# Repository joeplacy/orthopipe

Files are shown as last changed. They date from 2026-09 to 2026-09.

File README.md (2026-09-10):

# OrthoPipe

OrthoPipe is a production-oriented internal tool for orthotics fabrication labs. It turns a
3D foot scan plus a structured or free-text prescription into a validated, reviewer-approved,
print-ready orthotic STL with a traceable record from intake through approval.

The repository is an engineering prototype, **not yet a production or clinically validated
system**. Synthetic geometry passes today; real-world calibration, workflow validation, access
control, durable storage, and printer/material process validation remain release gates. See
[`docs/production-readiness.md`](docs/production-readiness.md).

## What exists

- Scan cleanup, canonical alignment, heightfield shell generation, prescription modifications,
  variable-stiffness lattice support, geometric checks, and a pressure proxy.
- FastAPI review station for upload, prescription review, generation, approval, download,
  complaint capture, and replay scorecards.
- Cloud and explicitly selected local Rx-parser backends.
- Historical-order replay/diff harness and landmark calibration tools.
- Deterministic bilateral print preparation with multi-body STL and manufacturing manifest.
- Offline Rx evaluation fixtures and a stdlib regression suite.
- De-identification guards for replay inputs and phone-scan normalization helpers.

## Local setup

Requires Python 3.11. The dependency versions in `requirements.txt` are pinned to the validated
baseline.

```bash
make setup
make verify
make demo
```

To start the local review station:

```bash
# Use .env.example as a reference; export overrides in your shell/process manager.
make serve
```

The server binds to `127.0.0.1:8000` by default. `ORTHOPIPE_DATA_DIR` moves runtime uploads and
outputs outside the source tree. Do not expose the server to a network until authentication,
authorization, TLS, and durable audit storage are implemented.

## Common commands

| Command | Purpose |
|---|---|
| `make verify` | Unit tests, parser self-check/offline evaluation, replay identity check |
| `make demo` | Full synthetic scan → STL run for both feet |
| `make print-prep-demo` | Generate, orient, pair, and manifest the two demo orthoses |
| `make replay-synthetic` | Five-order replay/diff exercise in `outputs/replay/` |
| `python -m eval.score_rx --offline` | Score cached parser fixtures without an API key |
| `python -m landmarks --help` | Landmark measurement/calibration commands |

## Rx parsing and PHI

Geometry and offline evaluation require no model API key. Live parsing defaults to Anthropic and
requires `ANTHROPIC_API_KEY`; the local Ollama path is selected explicitly with
`ORTHOPIPE_RX_BACKEND=local`. Never commit keys or paste patient-identifying data into fixtures.
Before real PHI is processed, complete the data-handling controls in
[`docs/data-handling.md`](docs/data-handling.md) and confirm appropriate vendor agreements.

## Historical calibration input

The replay harness consumes one directory per de-identified order containing:

- `order.json` — non-identifying order ID, side, and optional shell settings
- `rx.json` — structured prescription
- `scan.obj`, `scan.stl`, or `scan.ply` — original scan geometry
- `reference.stl` — fabricator-approved final device

Start with [`examples/deidentified-order/README.md`](examples/deidentified-order/README.md).

## Repository map

| Path | Role |
|---|---|
| `schema.py` | Validated prescription contract |
| `geometry.py` | Cleanup → alignment → shell → mods → validation → export |
| `lattice.py` | Optional zoned lattice generation |
| `rx_parser.py`, `rx_backends.py` | Free-text prescription parsing |
| `app.py`, `static/index.html` | Review-station API and UI |
| `replay.py` | Historical replay and geometric scorecards |
| `print_prep.py`, `workflow.py` | Bilateral build layout and confirmed production states |
| `landmarks.py` | Landmark measurement and calibration |
| `eval/` | Offline parser evaluation |
| `tests/` | Fast regression and safety tests |
| `docs/` | Strategy, discovery, data handling, and readiness gates |

## Print preparation

The confirmed fabricator workflow stands each completed FO with its forefoot upward, places the
medial faces toward the center without contact, combines both objects for export, embeds them
`0.3 mm` into the Simplify3D bed, and generates supports at a `23°` threshold. OrthoPipe automates
the deterministic geometry portion and records the slicing values without pretending to generate
or approve G-code:

```bash
python print_prep.py \
  --left ORDER_left.stl \
  --right ORDER_right.stl \
  --order-id ORDER \
  --out outputs/ORDER_print_pair.stl \
  --profile config/print-prep.example.json
```

The output includes a multi-body STL, front/top layout preview, and JSON manifest. The manifest
deliberately blocks G-code release until supports, slicing, and visual toolpath QC are completed.
Printer bed dimensions remain unset—and bed fit is reported as unknown—until the real factory
profile is available.

## Product direction

The intended operating model is an internal tool for fabrication labs, with production readiness
rather than a demo as the objective. Fabricator workflow discovery and representative historical
orders are acknowledged inputs to later gates; they are not silently replaced with assumptions.

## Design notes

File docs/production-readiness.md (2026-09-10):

# Production readiness plan

## Product boundary

OrthoPipe is intended to be an **internal fabrication-lab tool**. A trained reviewer remains in
the loop and owns approval. The software may translate clinical intent and generate geometry, but
it must not silently resolve ambiguous prescriptions or present a geometric check as proof of
clinical effectiveness.

The current repository is a validated engineering baseline, not a production release.

## Release gates

### Gate 0 — Reproducible engineering baseline

Status: **implemented locally; CI activates after the repository is pushed.**

- Imported work captured in version control.
- Python version and direct runtime dependencies pinned.
- One-command verification (`make verify`) and full synthetic demo (`make demo`).
- Unit/contract checks for schema ranges, mutable defaults, scale normalization, PII scrubbing,
  parser dispatch, health reporting, and replay path handling.
- GitHub Actions workflow for every pull request and main-branch push.
- Runtime host, port, data directory, and upload-size limit are configurable.

### Gate 1 — Fabricator workflow confirmed

Status: **partially documented.** The intake, Meshmixer orientation/layout, Simplify3D support,
toolpath review, and G-code handoff path are captured in
[`fabricator-workflow-current-state.md`](fabricator-workflow-current-state.md). The separate
prescription-modification procedure, timings, exception paths, acceptance rules, equipment, and
system ownership remain outstanding.

Observe real work rather than relying only on an interview. Complete
[`workflow-discovery.md`](workflow-discovery.md), including the happy path, exception paths,
handoffs, decision authority, artifacts, timings, queue states, rework, and acceptance criteria.

Exit evidence:

- Current-state swimlane reviewed by the people who do the work.
- Measured baseline for touch time, elapsed time, first-pass yield, remake rate, and queue age.
- Explicit list of decisions OrthoPipe may automate, recommend, or must leave to a reviewer.
- Scanner, CAD, slicer, printer, material, and job-tracking integration inventory.

### Gate 2 — Historical calibration and technical validation

Status: **waiting for de-identified representative orders and physical process inputs.**

Use the replay format in [`examples/deidentified-order/`](../examples/deidentified-order/) and
sample across common device/Rx types, operators, scan sources, and known difficult cases.

Exit evidence:

- Dataset inclusion/exclusion rules and provenance recorded.
- Landmark error and geometric deviation thresholds approved by domain experts.
- Parser evaluation uses real, de-identified prescriptions and real model outputs—not placeholder
  fixtures.
- Printed coupon testing maps lattice family/density to the actual TPU, printer, orientation, and
  slicer profile.
- Generated devices are compared with accepted devices and destructive/bench tests where needed.
- Failure cases reliably stop for manual review.

### Gate 3 — Controlled lab pilot

Status: **not started.**

- Durable database/object storage replaces the in-memory job registry.
- Authentication, roles, reviewer identity/signature, session management, and least privilege.
- TLS, secrets management, backup/restore, retention/deletion policy, and audit export.
- Malware/file validation, resource limits, worker isolation, retry/idempotency, and job recovery.
- Approved scanner ingestion, slicer profile, printer/material lot tracking, and output labeling.
- Monitoring covers job failures, queue age, validation failures, approval latency, and storage.
- Rollback, incident response, complaint handling, and support ownership are rehearsed.
- Pilot runs in shadow mode before any generated output is used operationally.

### Gate 4 — Production release

Status: **not started.**

- Pilot exit thresholds met for a pre-agreed sample size and time period.
- Risk management, software validation, change control, training, and work instructions approved.
- Regulatory counsel confirms classification, establishment obligations, quality-system scope,
  complaint/MDR handling, labeling, and records requirements for the actual business model.
- Security/privacy review and any required BAAs or other vendor agreements are complete.
- Named owners exist for product, clinical/fabrication validation, quality, security, operations,
  and incident response.

## Decisions intentionally deferred

These choices should follow workflow discovery rather than be baked into the prototype:

- Job/status data model and integrations.
- Whether the unit of work is a patient, encounter, order, pair, foot, device, or print job.
- Required reviewer roles and approval/signature sequence.
- Scanner and CAD interoperability priorities.
- Automatic slicer/printer dispatch versus reviewed export.
- Lab-specific geometry defaults and allowed adjustment ranges.

## Current technical limitations

- `SCANS` and `RESULTS` are process memory and are lost on restart.
- Audit and complaint records are local JSONL, not transactional or access-controlled.
- No authentication, authorization, tenant separation, electronic signatures, or TLS termination.
- Upload processing is synchronous and geometry work is not isolated in a durable job worker.
- Print preparation stops at a multi-body STL and manifest. It does not open a Simplify3D factory
  file, generate supports/G-code, or perform the required visual toolpath approval.
- Pressure output is a deterministic proxy, not validated FEA or clinical pressure evidence.
- Landmark rules and geometry have not been calibrated against representative real orders.
- Offline parser fixtures are placeholder emulations and must not be quoted as production accuracy.
- Dependency pins reproduce the current environment but still require vulnerability/license review
  and a controlled update policy.
- The project has no declared top-level software license; ownership and distribution terms must be
  decided before use outside the authorized development team.

## Production success measures

Set numeric thresholds with the fabricator at Gate 1. At minimum track:

- First-pass acceptance and remake rate.
- Median and p95 touch time and order elapsed time.
- Manual interventions and reason codes per order.
- Parser abstention/`needs_manual` recall on ambiguous prescriptions.
- Landmark and surface-deviation distributions by scan source and device type.
- Generation failure, validation failure, and approval-reversal rates.
- Print failure and material waste per accepted device.

No metric should be optimized without a balancing safety/quality metric.

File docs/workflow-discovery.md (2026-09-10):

# Fabricator workflow discovery guide

The first written workflow has been mapped in
[`fabricator-workflow-current-state.md`](fabricator-workflow-current-state.md). Use this guide to
fill its known gaps rather than asking the fabricator to repeat the documented steps.

Use this during direct observation of at least one routine order and one difficult/rework order.
Do not record patient identifiers. Capture screenshots or sample files only after they are
de-identified and approved for use.

## Session information

- Lab / location:
- Date:
- Participants and roles:
- Order types observed:
- Approximate daily/weekly volume:
- Peak periods or backlog pattern:

## Current-state step table

Create one row for every action, wait, handoff, or decision. Record measured time where possible.

| # | Trigger/input | Person/role | Action and decision | Tool/equipment | Output/status | Touch time | Wait time | Failure/rework path |
|---|---|---|---|---|---|---:|---:|---|
| 1 | | | | | | | | |

For each step ask:

- What information is required before starting, and where does it come from?
- What do you inspect or measure? What causes you to stop or ask a clinician?
- Which values are rules, defaults, experience-based judgments, or lab-specific conventions?
- What gets typed or transferred again? Which formats and naming conventions are used?
- How do you know the step is complete? Who may override or approve it?
- What commonly goes wrong, and how is the problem discovered and corrected?

## Artifacts and systems inventory

| Artifact/system | Format/version | Source of truth | Contains PHI? | Created by | Consumed by | Retention |
|---|---|---|---|---|---|---|
| Prescription | | | | | | |
| Scan | | | | | | |
| CAD design | | | | | | |
| Slicer profile | | | | | | |
| Print job | | | | | | |
| Inspection/approval | | | | | | |
| Complaint/remake | | | | | | |

Record scanner model/export settings, CAD software/version, slicer/version/profile, printer model,
nozzle, orientation, TPU brand/grade/lot, post-processing, and measurement equipment.

## Decision inventory

Classify each decision only after the fabricator explains it.

| Decision | Inputs/evidence | Allowed range | Who decides | Frequency | Consequence if wrong | OrthoPipe role |
|---|---|---|---|---:|---|---|
| | | | | | | automate / recommend / require review / out of scope |

Pay special attention to landmark corrections, trim line, posting, heel cup, relief placement,
thickness, accommodation, material/stiffness, scan quality, left/right identity, and remake triage.

## Exceptions and rework

For each common exception capture frequency, detection point, responsible role, added time,
disposition, and whether the original data/output is preserved. Ask for anonymized examples of:

- Bad or incomplete scans.
- Contradictory/illegible prescriptions.
- Unusual anatomy or device combinations.
- CAD changes after review.
- Failed prints or post-processing defects.
- Fit complaints, clinician changes, and remakes.

## Acceptance criteria

Ask the fabricator to demonstrate—not only describe—how a part is accepted. Record objective
measurements separately from visual/tactile judgment. Include who can release a part, what is
recorded, and what evidence must remain linked to the order.

## Baseline measures

Collect a representative baseline before introducing automation:

- Touch and wait time by step.
- First-pass yield and remake rate.
- Orders per operator per day.
- Queue age and oldest-order age.
- Manual CAD adjustments per order and reason.
- Print failures, material consumed, and scrap.

## Close-out

Return a one-page current-state swimlane, system/artifact map, exception list, decision inventory,
baseline metrics, and prioritized pain points to participants for correction. Treat silence as
unreviewed, not approval.

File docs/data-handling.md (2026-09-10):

# Data handling baseline

## Until production controls exist

- Use synthetic or explicitly de-identified data only.
- Do not place names, dates of birth, MRNs, addresses, contact details, free-text patient notes,
  credentials, or API keys in the repository, fixtures, filenames, logs, screenshots, or issues.
- Treat foot scans as potentially identifying clinical data even after obvious text fields are
  removed. Store them only in an approved location with restricted access.
- Do not expose the development server beyond localhost.
- Do not send prescriptions or scans to a cloud model until the organization confirms its legal,
  privacy, security, and contractual basis, including any required BAA.

## De-identification intake check

Before accepting a historical order, verify:

- The replacement order ID cannot be mapped back to a patient by the development team.
- Mesh metadata and filenames contain no identifiers.
- JSON keys and values contain no direct identifiers or unnecessary dates/free text.
- The prescription contains only the clinical instructions required for evaluation.
- The approved reference STL contains no embossed patient/order identifier.
- The source organization authorized this secondary use and transfer.

The replay harness strips a small denylist of obvious JSON keys and clears mesh metadata. That is
defense in depth, not a certification that the source is de-identified.

## Production controls still required

- Documented data-flow and threat model.
- Identity, role-based access, tenant/lab boundaries, and reviewer attribution.
- Encryption in transit and at rest with managed keys.
- Approved secret manager and key rotation.
- Durable audit trail, access logs, tamper detection, and time synchronization.
- Data retention, legal hold, export, deletion, backup, and restore procedures.
- Vendor inventory, risk assessment, agreements, and incident notification terms.
- Incident response, breach assessment, disaster recovery, and periodic access review.
- Test data management and a prohibition on copying production PHI into development.

Exact HIPAA, state-law, FDA, and quality-system obligations must be confirmed for the deployed
business and data flows by qualified advisors.

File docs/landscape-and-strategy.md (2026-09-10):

# OrthoPipe — Landscape & Strategy

_Compiled from two adversarially-verified deep-research passes (46 sources, 330+ claims
extracted, 34 findings that survived 3-vote verification). Figures reflect sources as of
July 2026. Decision inputs, not legal or clinical advice._

A polished, shareable version of this report is published as an Artifact:
https://claude.ai/code/artifact/f71536a0-9d9a-4176-8b23-24b1d323fd7b

---

## The strategic read

**Your core bet is validated — but the wedge is narrower and sharper than "automation."**

Scan → print automation is **table stakes**: Materialise Phits, Aetrex/SOLS, HP Arize, and
Denmark's Sequence all ship it, some with pressure-plate fusion and "reorder in three clicks."
Competing on "we automate design" walks into incumbents.

The defensible combination — which **no competitor pairs together** — is:

1. **LLM-parsed free-text prescriptions** (every rival uses fixed forms),
2. a **deterministic, range-clamped, human-approved geometry engine with a full audit trail**, and
3. **per-zone variable-stiffness lattice interiors** driven by that prescription — which the newest
   peer-reviewed work shows cut peak plantar pressure **36–42%** vs uniform infill.

Reframe the pitch from "we automate insole design" to **"we turn a prescription sentence into a
validated, pressure-optimized, printable part with a traceable record from words to STL."** That's
a claim about trust and clinical intent, not just throughput — the one thing form-driven black-box
pipelines can't easily copy.

---

## 1 · Competitive landscape

Two axes decide the field: how prescriptions **enter** (manual form → AI/free-text), and who **owns
the geometry** (hand-CAD → fully automated). OrthoPipe's open water is automated geometry **plus**
language-native intake, with auditability as the differentiator.

| Player | What it is | Intake | Pricing (verified) | Gap you exploit |
|---|---|---|---|---|
| **Wiky** (wikyapps.com) | Cloud podiatry platform: scan → design → manufacturing hand-off. The named target. | 4-step **fill-out form**; no AI/NLP in its marketing | pay-per-scan (undisclosed) | No free-text/LLM Rx; design is template/manual CAD |
| **Materialise Phits** | Footscan pressure plates + 3D scan drive **multi-density** insoles; mature EU Class IIa. | Form + pressure; SAM iOS scan is an *adjunct* (plate still required) | enterprise (undisclosed) | Hardware-heavy; no language intake; closed design logic |
| **Aetrex / SOLS** | B2B scan-to-print: Albert 2 Pro → EOS printing, 2–3 wk. Acquired SOLS 2017. | Scanner-driven; no local geometry control | B2B service | Outsourced & opaque; no in-clinic iteration or audit |
| **HP Arize** | Fully outsourced: scan → submit to HP → inserts mailed back. | Scan only; no local design/print | per-device | Zero clinician control; pilot RCT favored *traditional* at 8 wks |
| **Sequence** (Denmark) | **Closest AI rival:** ML on 20,000+ measurements predicts target shore hardness & shape from scan + gait, 10 pressure zones. | Scan + dynamic pressure → ML | commercial | Data-driven, not *intent*-driven; no clinician-language channel |
| **Gensole** (Gyrobot, UK) | Closest free tool: browser designer, morphs upper to scan ("Solemorph"), density zones via slicer. | Manual; **explicitly no Rx corrections** — deform scan by hand first | free, non-commercial; 2016-era, decaying | Its own docs admit the exact gap your Rx engine fills |
| **OrthoCAD** (Vertex) | Traditional orthotic CAD workstation software. | Manual CAD | **$1,500/yr** start, up to $12,999 perpetual | Pure manual CAD; the "software-only" price floor |

**Scanner ecosystem note:** Structure Sensor Pro (~$1,000, widely adopted in O&P) already ships
**automatic 8-landmark foot detection** in SDK 3.5.0 (acropodion, pternion, heel, 1st/last met, met
fibulare/tibiale, arch apex) — a COTS alternative to building landmarking yourself. COMB and
Materialise SAM both prove **phone-scan-only** (TrueDepth) intake in production.

---

## 2 · Open-source head start (license-aware)

You plan to ship a product, so: permissive (MIT/Apache) is drop-in, GPL is **server-side-only** safe
(GPLv3 has no network clause), "unknown" is a stop sign until the LICENSE file is read directly.

| Component | License | Does | Verdict |
|---|---|---|---|
| **PyMeshLab** (cnr-isti-vclab) | GPL-3.0 | Close-holes, decimate, smooth via MeshLab | **Adopt now.** Already in `requirements.txt`, not yet called. Unblocks real (hole-riddled) scans. Server-side use avoids copyleft. |
| **ampscan** (abel-research) | **MIT** | P&O scan analysis; ICP rigid alignment | **Vendor & adopt.** ICP > PCA for template-to-scan registration. Dormant since 2023 → copy the module in. |
| **CadQuery** | **Apache-2.0** | Parametric B-rep CAD (OCCT); STEP/DXF/STL/AMF/**3MF** | **Adopt** for crisp posts/trims the heightfield can't express, and 3MF export to the slicer. Safest license. |
| **microgen** (3MAH) | GPL-3.0 | TPMS gyroid/Diamond/Primitive via SDF + marching cubes; CAD-optional in 2.0 | **Strong, server-side.** Matches the zone→lattice research exactly. Pulls VTK/gmsh. |
| **Scaffolder / PyScaffolder** (nodtem66) | **unverified** | Mesh → TPMS gyroid | **Hold.** MIT claim failed verification; **no macOS wheels**. Read LICENSE first; else prefer microgen. |
| **trimesh SDF lattice** (build-your-own) | yours | Gyroid/Diamond/Primitive as analytic implicit fields | **Clean long-term play.** ~150 lines, no license entanglement, full gradient control. Prototype with microgen, then internalize. |

---

## 3 · Academic findings that should change the engine

Current engine = heightfield shell + flat bottom. The literature points to a **shell wrapping a
zoned, variable-stiffness lattice interior** — plus some assumptions to un-learn.

1. **Zoned lattices beat uniform infill — measurably.** Partition-infilled TPMS cut peak plantar
   pressure **~36% static / ~42% dynamic gait** vs uniform gyroid (30–37% lower mean in gait).
   _(Frontiers Bioeng. 2026)_ → **The single biggest product lever.** Shell + per-zone lattice.
2. **A concrete zone → lattice map.** Stiffness ranks **Diamond > Gyroid > Primitive**. Soft
   **Primitive → heel** (deform, spread contact), **Gyroid → forefoot**, stiff **Diamond → toe +
   midfoot**. → Bake as the default map in `apply_mods`; let Rx nudge it.
3. **Blend stiffness smoothly, don't step it.** Graded TPU gyroids last longest under fatigue with
   moderate, smooth gradients; abrupt jumps degrade fatigue life. _(Mech. Adv. Mater. Struct. 2025,
   cushioning study — extrapolated)_ → Interpolate lattice density across Rx zone boundaries.
4. **Gyroid isn't automatically best.** In TPU, **honeycomb** gave the highest compression load at
   50% strain and most energy absorption; **gyroid was lowest**. → Make lattice *family* a schema
   parameter, not a hardcoded gyroid.
5. **Bench stiffness ≠ in-gait pressure.** Honeycomb vs gyroid at 20% infill showed no significant
   in-shoe pressure difference vs no insole; an n=21 pilot even saw *increased* met pressure. → Add a
   pressure-based validation check (simulated or plate-fused); geometric pass ≠ clinical proof.
6. **"3D-printed" is not automatically better.** A pilot RCT favored **traditional** over HP Arize at
   8 wks (PROMIS function 49.0 vs 41.9). → Compete on speed, cost, traceability, and
   pressure-optimization — not material superiority.

---

## 4 · US regulatory footing

Custom foot orthotics are generally **Class I, 510(k)-exempt** — no premarket submission. Nuances:

**What holds**
- 510(k)-exempt, Class I.
- **GMP-lite:** exempt from most of 21 CFR 820 *except* recordkeeping & complaint files (§820.35).
  Your append-only audit log is the right instinct — extend to complaint handling.
- You're **"patient-matched," not "custom"** — FDA treats scan-fit-within-cleared-specs devices as
  patient-matched → normal (exempt) path, *not* the Custom Device Exemption.

**Where it bites**
- **Don't lean on the Custom Device Exemption** (§520(b)): capped at **5 units/yr per device type** —
  useless for volume.
- **Central fabrication = you're a manufacturer** (registration + GMP-lite + MDR reporting). Only
  dispensing-only retail O&P is registration-exempt (§807.65(i)) — not you.
- **Confirm the exact product code.** §890.3025 (accessories) does *not* classify a foot orthosis;
  the real code is a shoe-insert / arch-support classification.

**PHI angle on the Rx parser:** prescriptions can carry PHI. Sign a **BAA** for the Claude API and/or
ship a **local-LLM fallback** — a local Llama-70B extracted explicit clinical features at **95–100%
sensitivity**, so on-prem parsing is realistic where cloud is forbidden.

_Not legal advice. Confirm the FDA product code and consult a regulatory specialist before market._

---

## 5 · Head-start moves, ranked by impact ÷ effort

| # | Move | Effort | Impact | Why |
|---|---|---|---|---|
| 1 | **Wire PyMeshLab into `clean_scan`** | low | high | Already a dep, unused. Real scans are hole-riddled; #1 blocker to real data. |
| 2 | **Adopt ICP alignment from ampscan** | low | med-high | ICP > PCA for registration on real feet. MIT; vendor the module. |
| 3 | **Formalize audit + complaint record to §820.35** | low | med | You're 80% there; regulatory moat + trust story. |
| 4 | **Local-LLM fallback + Claude BAA** | med | med | De-risks the one AI dependency legally (PHI). |
| 5 | **Per-zone variable-stiffness lattice interior** | high | high | **The product.** Primitive-heel / Gyroid-forefoot / Diamond-toe-midfoot, smooth gradients. The 36–42% pressure claim, realized. Prototype with microgen, then trimesh SDF. |
| 6 | **Surface lattice family + density in the Rx schema** | med | high | Lets the LLM Rx actually drive the geometry the literature calls for. Extends your schema-as-contract. |
| 7 | **Add pressure-based validation** | high | high | Move "validation pass" from geometric to clinical. Closes bench≠gait gap; a review-UI edge over Phits. |
| 8 | **Phone-scan-only intake path** | med | med | COMB/SAM prove TrueDepth-only works. Removes scanner lock-in Aetrex/HP impose. |
| 9 | **Own the provenance story** | low | med | "Every part traceable from Rx sentence to STL." Nearly free; incumbents' black boxes can't answer it. |

---

## Method & open questions

**Method.** Two fan-out passes: parallel web search (5 angles) → source fetch & claim extraction →
**3-vote adversarial verification** (survives only if not refuted). 34 findings cleared the bar.
Dropped claims include a competitor's export formats and an unverifiable scanner-ecosystem detail.

**Still open — verify before betting the company:**
- The **exact FDA product code** for the device (drives the whole regulatory analysis).
- **Scaffolder's real license** — read the LICENSE file before adopting.
- Whether **any competitor beyond Wiky** ships free-text Rx (confirmed absent only for Wiky).
- Quantitative **lattice-density → shore-hardness** mapping in *your* TPU — validate on printed coupons.

### Key sources
- Frontiers Bioeng. 2026 — partition-infill TPMS · 10.3389/fbioe.2026.1820362
- Mech. Adv. Mater. Struct. 2025 — graded TPU gyroids · 10.1080/15376494.2025.2530146
- Foot & Ankle Ortho. 2026 — traditional vs HP Arize RCT · 10.1177/24730114251413246
- Preprints 2025 — TPU infill compression · 10.20944/preprints202503.0894.v1
- Sequence ML pipeline · 10.1177/11795972251371476
- Local-LLM clinical extraction · 10.1101/2023.12.07.23299648
- wikyapps.com/podiatry-wiky-solution · materialise.com/en/healthcare/phits-suite
- aetrexb2b.com/pages/3d-printing · gensole.com
- github: abel-research/ampscan · 3MAH/microgen · cnr-isti-vclab/PyMeshLab · cadquery/cadquery
- structure.io — automatic foot landmark detection (SDK 3.5.0)
- FDA: 21 CFR 890.3025 · §807.65(i) · custom device exemption §520(b)

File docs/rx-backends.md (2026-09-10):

# Rx parser backends

`rx_parser.parse_prescription` produces the same validated `Prescription` from a
pluggable inference backend. The Pydantic schema (`schema.py`) is the single
contract; only the inference path changes.

## Selecting a backend

Selection order: the `backend=` kwarg → the `ORTHOPIPE_RX_BACKEND` env var →
default `"anthropic"`.

| `ORTHOPIPE_RX_BACKEND` | backend | data leaves machine? | requires |
|---|---|---|---|
| _unset_ / `anthropic` | Anthropic Messages API (default) | yes (cloud) | `anthropic`, `ANTHROPIC_API_KEY` |
| `local` | Ollama, JSON-schema-constrained decode | **no** | `ollama` package + running Ollama server |

Extra knob: `ORTHOPIPE_RX_LOCAL_MODEL` picks the local model (default `llama3.1`).

```bash
# default cloud path (unchanged)
python -c "from rx_parser import parse_prescription; print(parse_prescription('4mm medial wedge left','ORD1').order_id)"

# fully local, PHI stays on the machine
ORTHOPIPE_RX_BACKEND=local ORTHOPIPE_RX_LOCAL_MODEL=llama3.1 \
  python -c "from rx_parser import parse_prescription; print(parse_prescription('softer heel, 4mm medial wedge, left foot','ORD2'))"
```

**Fail-loud, never silent-fallback:** an unknown backend name raises `ValueError`;
`local` selected without the `ollama` package or a reachable server raises
`RuntimeError` (and never constructs an Anthropic client). This is deliberate — a
PHI-safe deployment must never silently spill to the cloud.

## PHI on the cloud path (BAA)

Prescription free-text can carry PHI. If you must use the cloud backend with PHI,
confirm the current terms with Anthropic — as of writing:

- PHI is only permitted on the **Messages API under a signed Anthropic BAA**.
  The **Console/Workbench** and consumer **Pro/Team** plans are **not** covered by a BAA.
- **Covered Models** under the BAA require a **30-day retention** window, so
  **Zero-Data-Retention (ZDR) is not available** for them.

These are policy facts that change over time — **verify with Anthropic before
processing PHI**, and treat this doc as a pointer, not legal advice.

## PHI-safe default: local

The `local` backend runs entirely on-premise (Ollama / llama.cpp): no prescription
text leaves the machine, so a clinic can operate without a BAA. It uses the same
`SYSTEM_PROMPT`, with the model's decode constrained to the `Prescription` JSON
schema, then validated with `Prescription.model_validate_json`.

Optional deps are **not** in the default `requirements.txt` (see the commented
extras there); install `ollama` (and run a server) only for the local path.

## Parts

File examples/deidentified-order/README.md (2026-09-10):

# De-identified historical order template

Copy this directory, replace `EXAMPLE-001` with a non-identifying ID, and add exactly one scan file
named `scan.obj`, `scan.stl`, or `scan.ply` plus the fabricator-approved `reference.stl`.

Do not commit real order directories. Before transfer, follow
[`docs/data-handling.md`](../../docs/data-handling.md), including checking mesh metadata, filenames,
free text, and embossed geometry.

Run one order with:

```bash
python replay.py --orders /approved/path/to/EXAMPLE-001 --out outputs/replay
```

`order.json` must specify the side. `rx.json` may be a bare `FootRx` as shown here or a complete
`Prescription`. Create separate directories for left and right when each has its own scan/reference.

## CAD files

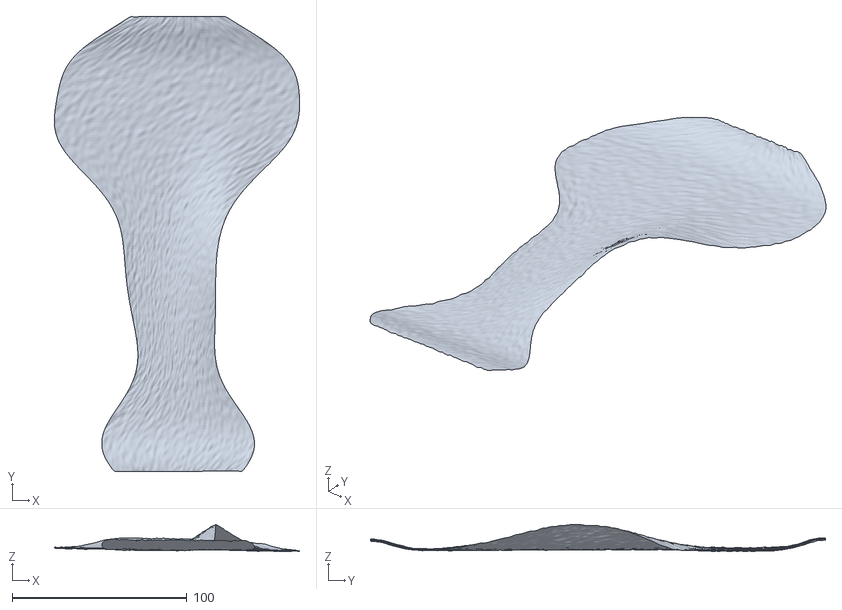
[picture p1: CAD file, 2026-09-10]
templates/right_foot_template.stl
140.3 x 260.3 x 15.5

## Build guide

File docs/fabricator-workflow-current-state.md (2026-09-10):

# Fabricator current state workflow

## Scope and confidence

This process map translates the fabricator's `Foot Orthotic Workflow.docx`, received September 10,
2026. It records what the document states and separates implementation inferences from confirmed
facts. The source contains no timings, screenshots, prescriptions, scans, finished orthoses,
printer details, or separate modification procedure.

## Confirmed workflow

| State | Confirmed activity | System or artifact | OrthoPipe status |
|---|---|---|---|
| Received | SplintFab sends scans by email; FOS uses oral/written notification | Email or notification | External intake; integration deferred |
| Files staged | A patient folder is created and scans are downloaded | OneDrive for SplintFab; Dropbox plus Comb Portal for FOS | Manual; PHI/source-of-truth controls unresolved |
| Scans oriented | Each scan is imported and oriented so plantar heel and metatarsals touch the Meshmixer bed as closely as possible | Meshmixer project | Bed-contact metric now reported; tolerance remains provisional |
| Design complete | Modifications are executed per specification for both orthoses | Separate workflow not yet supplied | Geometry exists, but equivalence is unvalidated |
| Print layout ready | Forefeet point upward, medial sides face the printer center, lowest points meet the bed, trimlines are close but not touching, and objects are combined/exported | Meshmixer multi-body export | Implemented as configurable `print_prep.py` output |
| Supports generated | Pair is imported into a Simplify3D factory file, moved `-0.3 mm` in Z, and automatic supports use a `23°` threshold | Simplify3D `.factory` file | Values recorded; slicing not implemented |
| Toolpath QC approved | Fabricator visually observes prepared G-code | Simplify3D preview | Required human gate; criteria unknown |
| G-code released | G-code is saved in the patient folder and emailed to SplintFab | G-code, folder, email | External release; deliberately blocked in current code |

## Implemented interpretation

`print_prep.py` applies one explicit interpretation of the repeatable Meshmixer operations:

- Canonical heel-to-toe `+Y` is rotated to vertical `+Z` so the forefoot points upward.
- Generated left and right geometry is placed on opposite sides of the centerline so both medial
  faces point inward.
- The requested space between axis-aligned bounds is enforced and verified.
- The pair is exported as one STL containing two disconnected bodies. It is not boolean-unioned.
- The documented `0.3 mm` bed embed and `23°` support threshold are stored in the manifest.
- Optional printer build dimensions can turn bed fit into an actual check once supplied.

The exact rotation and packing must be compared with the requested real completed FO or a prepared
Meshmixer/Simplify3D screenshot before this interpretation is treated as validated.

## Confirmed filename and data behavior

The current filename embeds patient ID, description/modification shorthand, `FO MM`, and date. This
is unsuitable for development fixtures and may expose PHI when files are emailed or copied. The
OrthoPipe implementation uses a constrained non-identifying order ID and records hashes and
transform matrices in a separate manifest.

## Required next evidence

Highest value first:

1. One de-identified foot scan and its corresponding completed FO ready for print.
2. The separate Meshmixer modification workflow referenced by the source document.
3. The Simplify3D `.factory` file or screenshots of the imported, supported pair and toolpath.
4. Printer model/build volume, nozzle, material, layer settings, and print orientation rationale.
5. The fabricator's visual G-code approval and finished-part acceptance criteria.
6. Clarification of FOS and which system is authoritative for order status and released files.

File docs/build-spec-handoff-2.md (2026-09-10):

# OrthoPipe — Implementation Handoff #2

## You are working on

**OrthoPipe** is a pipeline that turns a 3D foot scan (`.obj`) plus a clinician prescription into a validated, 3D-print-ready orthotic STL.

**Stack:** Python, `trimesh`, `pymeshlab`, `pydantic`, `FastAPI`.

**Key files:**
- `schema.py` — Pydantic Rx contract (the LLM↔geometry interface), now including optional per-zone `fill`.
- `geometry.py` — the engine: cleanup → align → heightfield → shell → mods → validate → export.
- `rx_parser.py` — Claude-powered free-text Rx → `Prescription`.
- `app.py` — FastAPI review UI + audit log.
- `vendor/` — MIT-licensed ampscan ICP.
- `templates/` — canonical foot template.

**Dev loop:**
```bash
source .venv/bin/activate
python run_demo.py   # end-to-end geometry check (must keep passing), ~12s
python app.py        # serves review UI on :8000; copies index.html -> static/index.html
```

## This is handoff #2

A **first handoff** already specced: mesh-cleanup, ICP alignment, the lattice/fill schema, a lattice generator, and the audit/complaint log.

Before starting any item here, **VERIFY the state of that prior work directly in the code.** Do **not** re-implement anything already done. Where an item below depends on a batch-1 deliverable and that deliverable is incomplete or absent, implement against the **current reality of the repo** and **note the assumption inline** in your code/comments. (Several sections already flag likely gaps — e.g. lattice may be absent, eval modules may be absent — treat those flags as hypotheses to confirm, not facts.)

## How to work

- **Smallest change per spec.** No unrelated refactors, no drive-by cleanups.
- **Preserve public signatures and return shapes.** In particular: `generate_orthotic`'s 6-tuple return `(solid, aligned, hf, top, mask, report)`, and `validate`'s existing report keys (`pass`, `checks`, `volume_cm3`, `extents_mm`, `est_print_mass_g_tpu`, plus the `.update()`-ed `side`/`mods_applied`/`warnings`/`foot_length_mm`/`output`).
- **After each item, run `python run_demo.py`** and confirm `report["pass"] is True` (watertight, positive volume, plausible dims) before moving to the next.
- **Match existing code style.**
- **Any new dependency goes in `requirements.txt` AND must be optional/light.** These items must not make the core pipeline heavier to import — optional deps are lazy-imported and degrade gracefully when absent.
- **Prefer tools that run with NO `ANTHROPIC_API_KEY`** so CI can exercise them.
- **Ask nothing.** Implement to spec; when the spec says "confirm in code," confirm it; where you must assume, note the assumption inline.

## One-line map

Item **1 (replay + diff harness)** is the keystone that unblocks calibration. Items **2–3 (landmark accuracy, Rx eval)** are the calibration/measurement layer that feeds it. Item **4 (pressure validation)** makes `pass` clinically meaningful. Item **5 (local-LLM fallback)** de-risks PHI. Item **6 (phone-scan)** is GTM-facing and independent. **Do item 1 first; items 2–4 build on it.**

---

# 1. Historical-order replay + geometric diff scorecard

**Objective.** Add a standalone `replay.py` module + CLI that runs a directory of historical orders (scan + Rx + accepted reference STL) through `generate_orthotic`, aligns each produced STL to its reference, and emits a per-order geometric-diff scorecard (surface deviation stats, deviation heatmap PNG, volume delta, clinical cross-sections, landmark deltas) plus an aggregate summary — with a synthetic-pair generator so it runs today against zero real data.

**Why it matters.** Turns the engine from "produces a plausible part" into "measurably close to accepted clinical output," unblocking all downstream calibration.

**Files to touch**
- `/Users/sam/Documents/Claude/Orthopipe/replay.py` — **NEW** (module + `if __name__ == "__main__"` CLI).
- `/Users/sam/Documents/Claude/Orthopipe/synthetic_foot.py` — extend (or add a sibling helper in `replay.py`) to emit a perturbed "reference" STL. The current entrypoint is `make_foot_scan(length_mm, width_mm, side, ...)` — call it by that signature.
- `/Users/sam/Documents/Claude/Orthopipe/geometry.py` — **READ ONLY**, reuse `generate_orthotic`, `align_canonical`, `refine_icp`, `Heightfield`. Do not modify.
- `/Users/sam/Documents/Claude/Orthopipe/static/index.html` + `/Users/sam/Documents/Claude/Orthopipe/app.py` — **NEW** small additive surface: one read endpoint + a heatmap/"diverges from historical norm" panel. Keep existing routes/response shapes intact.

**Exact approach**

1. **Order ingestion.** Define an order as a directory containing: `scan.obj` (or `.stl`/`.ply` — the loader path already tolerates these), a reference STL (the accepted/fabricator part, e.g. `reference.stl`), and the driving Rx as `rx.json` (a serialized `Prescription` or per-foot `FootRx`) and/or `rx_text`. Read `side` and `order_id` from a small `order.json` (or infer `order_id` from the directory name; require explicit `side ∈ {"left","right"}`). If only `rx_text` is present and no `rx.json`, treat parsing as optional — see guardrail on `ANTHROPIC_API_KEY`.

2. **De-identification guard.** Before doing anything, scrub/refuse PII. Operate on geometry only: load meshes with `trimesh.load(..., force="mesh")` and never propagate mesh `metadata`. For the JSON sidecars, drop any key matching an obvious-PII denylist (`name`, `dob`, `mrn`, `patient`, `ssn`, `address`, `phone`, `email`, case-insensitive) and, if such keys are found, record `"pii_scrubbed": [<keys>]` in the per-order output rather than failing silently. Only `order_id`, `side`, geometry, and clinical Rx fields survive downstream.

3. **Run the engine.** For each order, build `FootRx(**rx_for_side)` and `Shell(**shell_dict)` (defaulting to `Shell()`), then call the existing entrypoint verbatim:
   ```python
   solid, aligned, hf, top, mask, report = generate_orthotic(scan_path, side, foot_rx, shell, out_stl)
   ```
   Keep all six return values; you need `solid` (produced part), `hf` (for landmark rows/`cell`/`L`), and `report` (surface into the scorecard). Write the produced STL to an output dir keyed by `order_id_side`.

4. **Align produced → reference.** Load the reference STL. Reuse the alignment path: since `generate_orthotic` already runs `align_canonical(..., use_icp=True)` on the *scan*, the produced part is in canonical frame but the reference may not be. Rigid-align the reference to the produced part (or vice versa) using the vendored ICP the repo already imports — `from vendor.ampscan_icp import register_icp` — mirroring how `refine_icp(mesh, template)` calls `register_icp(mesh.vertices, mesh.faces, template.vertices, template.faces)` and returns `(transformed_mesh, rmse)`. If ICP fails or residual is implausible, fall back to a coarse rigid PCA/centroid align and record `"align_fallback": true`. Record the final alignment `rmse`.

5. **Surface-deviation scorecard.** With reference mesh `A` and produced mesh `B` (post-align), compute per-vertex signed deviation and stats:
   ```python
   d = trimesh.proximity.signed_distance(A, B.vertices)   # (len(B.vertices),) mm, signed
   ad = np.abs(d)
   mean_dev, p95 = float(ad.mean()), float(np.percentile(ad, 95))
   ```
   Hausdorff (trimesh has no builtin — compute both one-sided directions via `trimesh.proximity.closest_point` and take the max):
   ```python
   def one_sided(src, dst):
       _, dist, _ = trimesh.proximity.closest_point(dst, src.vertices)
       return float(dist.max())
   hausdorff = max(one_sided(A, B), one_sided(B, A))
   ```
   `rtree`/`manifold3d` are already hard deps in `requirements.txt`, so the watertight signed-distance path works out of the box. Keep a defensive fallback anyway: if `signed_distance` is unavailable, fall back to unsigned `closest_point(A, B.vertices)` distances for the heatmap and stats and set `"signed": false`. Sample the surface for a denser Hausdorff only if needed (`trimesh.sample.sample_surface`).

6. **Deviation heatmap PNG.** Reuse `run_demo.py`'s **exact** preview-render path, which is **matplotlib Agg** (`matplotlib.use("Agg")`, `ax.imshow(...)`, `fig.savefig(...)`). There is **no 3D mesh renderer** in the stack, and `trimesh.Scene.save_image` needs pyglet/OpenGL, which is **not** in `requirements.txt` and won't run headless — do **NOT** use `scene().save_image` or `visual.vertex_colors`. Instead, rasterize per-vertex `abs(d)` onto the `Heightfield` grid (bin each produced-vertex XY into a `(hf.ny, hf.nx)` array — take mean/max `abs(d)` per cell, NaN off-mask — or use a 2D scatter of vertex XY colored by `abs(d)`), then render with matplotlib:
   ```python
   import matplotlib
   matplotlib.use("Agg")
   import matplotlib.pyplot as plt
   fig, ax = plt.subplots()
   im = ax.imshow(dev_grid, cmap="viridis")   # dev_grid = abs(d) rasterized onto the hf grid, NaN off-mask
   fig.colorbar(im, ax=ax, label="|deviation| (mm)")
   fig.savefig(png_path)
   plt.close(fig)
   ```
   Confirm the exact `matplotlib` calls `run_demo.py` uses for its preview PNGs and mirror them so the two render paths stay consistent.

7. **Volume delta.** Use the `volume` property, guarded by watertightness (both `generate_orthotic`'s `validate` and the produced solid already care about this):
   ```python
   vol_delta_cm3 = round((B.volume - A.volume) / 1000.0, 2)  # +added / -removed material
   ```
   Only trust the sign if `A.is_watertight and B.is_watertight`; otherwise report magnitude with `"volume_watertight": false`.

8. **Clinical cross-sections** via planar sections on the produced part, using `Heightfield` landmark rows to place the planes. `hf.landmark(name)` returns `(row, col)` in grid units; convert a row to a world Y with `hf` geometry (`cell = CELL_MM = 2.0`, heel at `y=0`; confirm exact `y_heel`/`cell` world mapping in `Heightfield.__init__`). Then:
   - **Arch height:** transverse-ish section through `landmark("arch_apex")`; take the section's vertical span. Use `mesh.section_multiplane(origin, normal, heights)` for efficiency and read each `Path2D.extents[1]` (vertical bbox span) as the height metric.
   - **Heel-cup depth:** section through `landmark("heel_center")`; depth = rim height minus cup-floor along the section's vertical extent (from `Path2D.bounds`).
   - **Rearfoot / forefoot posting angle:** fit a line to the bottom (z≈0 posting face) of a heel-region section vs a forefoot-region section and report the tilt in degrees. Compute the same metrics on `A` and `B` and emit deltas.
   Cross-section snippet:
   ```python
   secs = mesh.section_multiplane(plane_origin, plane_normal=[0,1,0], heights=[...])  # list[Path2D|None]
   ```
   Skip gracefully (`None` section) if a plane misses the mesh.

9. **Landmark-position deltas.** For each accepted name (`heel_center`, `base_5th_met`, `met_heads`, `arch_apex`, `hallux`), map `hf.landmark(name)` `(row,col)` to a world XY on the produced part, find the nearest reference-surface point via `trimesh.proximity.closest_point`, and report the 3D delta magnitude per landmark.

10. **Emit outputs.** Per order: `<order_id>_<side>_scorecard.json` (all stats above + `rmse`, `pii_scrubbed`, feature-availability flags + the engine's own `report` dict embedded for provenance) and the heatmap PNG. Aggregate: `replay_summary.json` with per-order rows and dataset-level mean/median of `mean_dev`, `p95`, `hausdorff`, plus a **`diverges_from_norm`** boolean per order (flag when an order's `p95` or `hausdorff` exceeds `median + k·MAD` across the batch, `k` configurable, default ~3). This flag is the provenance/traceability surface.

11. **Synthetic-pair generator (zero real data).** Add a `--synthetic N` CLI mode: for each of N orders, generate a fake scan via `synthetic_foot.py`, run it through `generate_orthotic` to get a "produced" part, then create the **reference** as a *slightly perturbed* copy of that produced STL (small rigid offset + mild vertex noise / a scale nudge) so deviations are nonzero but bounded. Write each into an order directory the ingestion path in step 1 accepts, then run the normal replay over them. This must run with no `ANTHROPIC_API_KEY` (Rx supplied as `rx.json`, not parsed).

12. **Review-UI / report surface.** Add one additive read endpoint to `app.py`, e.g. `@app.get("/api/replay/{order_id}")` returning the scorecard JSON + heatmap URL (follow the existing `FileResponse` pattern used by `/api/stl/{result_id}`; do not touch `approve`, `generate`, or their response shapes). In `static/index.html`, add a panel that shows the deviation heatmap and a red **"diverges from historical norm"** badge when `diverges_from_norm` is true. Keep it behind the existing static mount.

**Backward-compat / guardrails**
- Do **not** change `generate_orthotic`'s 6-tuple return `(solid, aligned, hf, top, mask, report)` or its signature — consume it as-is.
- Do **not** alter `validate`'s report keys (`pass`, `checks`, `volume_cm3`, `extents_mm`, `est_print_mass_g_tpu`, plus the `generate_orthotic` `.update()` keys); only *read* `report` into the scorecard.
- `run_demo.py` must still run unchanged (`python run_demo.py`, ~12 s). `replay.py` is additive; no imports of it from the existing pipeline.
- `app.py`: existing endpoints, in-memory `SCANS`/`RESULTS`, and the inline audit write stay exactly as they are; only add the new read endpoint + static panel.
- Keep deps light: `trimesh`/`numpy`/`scipy` are already in `requirements.txt`, and `rtree`/`manifold3d` (signed-distance acceleration) are already hard deps too, so the signed/watertight path works without adding anything. Keep the unsigned `closest_point` fallback as defensive dead-safety and flag it when it fires. No new hard dependency.
- De-id is mandatory: never write patient-identifying keys into any scorecard/summary/audit output.

**Acceptance criteria**
- `python replay.py --synthetic 5 --out /tmp/replay_out` runs **with no `ANTHROPIC_API_KEY` set** and exits 0, producing 5 `*_scorecard.json`, 5 heatmap PNGs, and one `replay_summary.json`. Verify: `test -f /tmp/replay_out/replay_summary.json && ls /tmp/replay_out/*_scorecard.json | wc -l` → `5`.
- Each scorecard JSON contains numeric `mean_dev`, `p95`, `hausdorff` (mm), `vol_delta_cm3`, a `cross_sections` object (arch height, heel-cup depth, rearfoot/forefoot posting deltas), a `landmark_deltas` object with all five landmark names, `rmse`, and a boolean `diverges_from_norm`. For synthetic pairs the deviations are small and bounded (e.g. `p95 < ~2 mm` given a mild perturbation — tune the perturbation so this holds).
- Feeding **identical** meshes (reference == produced) yields `mean_dev ≈ 0`, `hausdorff ≈ 0`, `vol_delta_cm3 ≈ 0` — a sanity assertion the CLI can self-check with a `--selftest` flag.
- De-id: dropping a `patient`/`mrn` key into an order's `rx.json` results in `pii_scrubbed` listing those keys and their absence from every output file.
- `python run_demo.py` still completes and writes its STLs/preview PNGs unchanged.
- With `app.py` running (`python app.py`), `GET /api/replay/<order_id>` returns the scorecard JSON and the heatmap renders in `static/index.html` with the divergence badge appearing for a deliberately over-perturbed synthetic order.

**Effort: L** — one new module plus a synthetic-data harness, ICP reuse, multi-metric geometry (sections + Hausdorff + heatmap render), and a small additive UI/endpoint; each piece is straightforward against existing deps but there are many pieces and a render/optional-dep fallback path to get right.

---

# 2. Landmark accuracy: measurement, calibration, optional learned detector

**Objective.** Add a way to measure how far the current `Heightfield.landmark()` proportional guesses fall from ground-truth landmark positions (in mm), calibrate those ratios/offsets against real data, and (optionally, off by default) scaffold a small learned detector — without touching `generate_orthotic`'s default landmark path unless a regression proves synthetic mods still land correctly.

**Why it matters.** Every mod in `apply_mods` (heel_lift, medial/lateral_wedge, met_pad, relief) is positioned by row/col from `landmark()`; wrong landmarks silently produce a wrong part.

**Files to touch**
- `landmarks.py` — **NEW**: annotation format + loader, measurement pass, calibration fit, and (isolated, optional) learned-detector scaffold.
- `annotations/` — **NEW** dir: one JSON per annotated aligned scan (ground-truth landmark coords). Add to `.gitignore` if scans carry PHI; confirm in code.
- `geometry.py` — **edited**: step 4 extracts the hardcoded fractions inside `landmark()` into a `LANDMARK_PARAMS` data structure that `landmark()` reads. This is an in-place refactor of `landmark()`, but it must be **byte-identical by default** — the extracted defaults equal the current constants, so behavior is unchanged until someone opts into a calibration file (the guardrail + regression below enforce this). Only the default-values-preserved extraction is in scope; `Heightfield`, `align_canonical`, `clean_scan` are otherwise read-only reference.
- `run_demo.py` — read-only reference (regression harness); do not change its output contract.
- `requirements.txt` — no new required deps; learned-detector extra is optional/commented (see guardrails).

**Exact approach**

1. **Annotation format + loader.** One JSON per aligned scan. Landmark names MUST be exactly the five from the `Landmark` alias / `Heightfield.landmark` accepted set: `heel_center`, `base_5th_met`, `met_heads`, `arch_apex`, `hallux`. Store ground truth in **aligned-frame mm** (post-`align_canonical`, so heel y=0, plantar z=0, x=median), because `landmark()` operates on the aligned `Heightfield`:
   ```json
   {"scan": "uploads/97ffe523_sample_scan_right.obj", "side": "right",
    "landmarks": {"heel_center": [x_mm, y_mm], "met_heads": [x_mm, y_mm], ...}}
   ```
   Loader `load_annotation(path) -> dict`. Only the `(x_mm, y_mm)` plantar-plane position is needed for error (landmark returns `(row, col)` → grid indices; z not used).

2. **Grid↔mm conversion (needed to compare).** `Heightfield.landmark(name)` returns `(row, col)` = `(j, i)` ints into the `(ny, nx)` grid with `cell = CELL_MM = 2.0`. Convert a grid index to aligned mm using the field's origin. `y_mm = y_heel*... ` — the exact grid-origin mapping (whether row 0 corresponds to y=0 or to `y.min` bin) is **confirm in code** by reading `Heightfield.__init__` (L252) for how `y_heel`/`y_toe`/`cell` map rows to mm; implement one helper `grid_to_mm(hf, row, col) -> (x_mm, y_mm)` and unit-check it against `heel_center` (should land near y≈`row_at(0.10)*cell`). Do NOT invent an `xn()` helper — it is ABSENT.

3. **Measurement pass.** `measure(annotations, use_icp=True) -> dict`. For each annotated scan: `trimesh.load` → `clean_scan` → `align_canonical(scan, side)` → `Heightfield(aligned)` (mirror the exact `generate_orthotic` preprocessing so measured error reflects production). For each landmark: `grid_to_mm(hf, *hf.landmark(name))` vs ground truth; per-landmark euclidean error in mm. Report per-landmark mean / p95 / max across the set. This step needs **no `ANTHROPIC_API_KEY`** (pure geometry).

4. **Calibrate the heuristics.** The heuristics are the hardcoded fractions inside `landmark()`: `row_at(f)` fractions (0.10/0.63/0.72/0.45/0.90) and the col offsets (`cols.min()+1`, `cols.max()-len(cols)//4`, etc.). Refactor these constants out of `landmark()` into a single data structure (e.g. `LANDMARK_PARAMS: dict[str, dict]`) that `landmark()` reads, so calibration can fit them. **This edits `landmark()` in place, but the extracted defaults MUST equal the current constants so the default path is byte-identical** (see guardrails + the regression that enforces it). Fit each landmark's row-fraction (and col rule where parameterizable) by least-squares / scalar minimization against the mm ground truth — 1-D per parameter, no heavy solver (stdlib/`numpy`/`scipy.optimize.minimize_scalar` — `scipy` is already a dep). Write fitted params to `landmark_calibration.json`. Re-run `measure()` with calibrated params; report before/after per-landmark error delta.

5. **OPTIONAL learned detector (off by default, isolated).** In a clearly separated block/class `LearnedLandmarkDetector` in `landmarks.py`: features from the aligned `Heightfield.Z`/`mask` arrays → landmark coords. Guard **all** ML imports behind a lazy import inside the method so importing `landmarks.py` never pulls ML deps; default construction/measurement path must not import them. Gate activation behind an explicit flag (e.g. `detector="heuristic"` vs `"learned"`), default `"heuristic"`. Any ML dep (scikit-learn or similar) goes in an optional/commented `requirements.txt` line, never a hard import.

6. **Feed error into the replay scorecard.** The replay/scorecard module is ABSENT today (see inventory — no `replay`/`eval` modules); spec `measure()` to return a plain dict of per-landmark mm errors so the (separately-spec'd) scorecard can `.update()` it in, mirroring how `validate`'s report is `.update()`-ed in `generate_orthotic`. Do not create the scorecard here; just expose the dict. (Note: item 1 lands `replay.py` — if it is already present when you reach this item, confirm the dict shape it expects and match it; otherwise implement to the shape above and note the assumption.)

**Backward-compat / guardrails**
- `generate_orthotic`'s return tuple stays exactly `(solid, aligned, hf, top, mask, report)` (6-tuple) — do not add or reorder.
- `validate`'s report keys stay unchanged (`pass`, `checks`, `volume_cm3`, `extents_mm`, `est_print_mass_g_tpu`); landmark error is NOT injected into `validate`'s dict.
- **Do NOT change the default landmark path.** Step 4's refactor edits `landmark()`, but calibrated values must default to the current constants (0.10/0.63/0.72/0.45/0.90 and current col rules) so behavior is byte-identical until someone opts into a calibration file. Swapping in fitted params as the default requires a passing regression proving mods still land on synthetic data (below).
- Keep deps light: `numpy`/`scipy`/`trimesh` only for core; ML deps optional and lazy. No new required dependency.
- `run_demo.py` must still run end-to-end (~12s) and produce STLs/PNGs unchanged.

**Acceptance criteria**
- `python run_demo.py` still completes and emits the same STL/PNG outputs (no ANTHROPIC_API_KEY needed). Confirm the 6-tuple and `report` keys are unchanged.
- `python -c "import landmarks"` succeeds with **no** ML packages installed (proves lazy-import isolation).
- A measurement command — e.g. `python -m landmarks measure annotations/` — prints a per-landmark mm error table (mean/p95/max) for the annotated set; runs with **no ANTHROPIC_API_KEY**. With a synthetic annotation generated from `synthetic_foot.py` (ground truth = the same proportional positions), measured error is ≈0 mm per landmark (sanity that grid↔mm conversion in step 2 is correct).
- A calibrate command — e.g. `python -m landmarks calibrate annotations/` — writes `landmark_calibration.json` and prints before/after per-landmark error; after ≤ before for every landmark on the fit set.
- Regression: with default (uncalibrated) params, a synthetic-scan run through `generate_orthotic` produces the same `top`/`mask`/mods as before the refactor (assert `applied` list and a checksum/max-diff of `top` unchanged) — proving step 4's extraction of constants is behavior-preserving.
- Learned detector remains inert: default measurement/calibration never instantiates `LearnedLandmarkDetector`; enabling it is an explicit flag.

**Effort: M** — measurement + calibration are small numpy/scipy over existing `Heightfield.landmark`; the real cost is the grid↔mm origin mapping (confirm in code) and building a trustworthy synthetic-regression harness; the learned detector is an isolated optional stub.

---

# 3. Rx parser evaluation harness

**Objective.** Add an offline-capable evaluation module that runs `parse_prescription` (or cached fixtures) over a labeled set of `(rx_text, expected Prescription)` cases and scores field-level accuracy: per-mod-type precision/recall, params within tolerance, side assignment, unit conversion, and `needs_manual` firing — emitting a summary plus a confusion list of failures.

**Why it matters.** The parser is currently validated against a single synthetic example; this is the only way to attach a number to accuracy, surface failure modes, and calibrate when `needs_manual` should fire.

**Files to touch**
- **NEW** `eval/__init__.py`
- **NEW** `eval/rx_dataset.py` — seed cases (typed, hand-written now; structured to ingest real de-identified Rx later)
- **NEW** `eval/score_rx.py` — scoring harness + CLI entry (`python -m eval.score_rx`)
- **NEW** `eval/fixtures/<case_id>.json` — cached `Prescription` JSON per case, captured from **real model output** (a live keyed run), for `--offline` (no `ANTHROPIC_API_KEY`)
- **NEW** `eval/README.md` — how to run, how to add real cases, last measured accuracy + `needs_manual` rate
- Do **not** modify `rx_parser.py`, `schema.py`, or `geometry.py`. (`parse_prescription(rx_text, order_id="ORDER") -> Prescription`, `MODEL`, and `SYSTEM_PROMPT` are consumed as-is.)

**Exact approach**

1. **Dataset shape.** In `eval/rx_dataset.py`, each case is `{case_id: str, rx_text: str, expected: Prescription, note: str}`. Build `expected` with real schema objects — `Prescription(order_id=..., left=FootRx(mods=[MedialWedge(degrees=5), HeelLift(height_mm=6)], fill=None), right=..., shell=Shell(...), needs_manual=False, ambiguities=[])`. Seed ~12–20 cases covering: single-side vs bilateral, each `Mod` type (`medial_wedge`, `lateral_wedge`, `heel_lift`, `relief`, `met_pad`), a `Relief` with each `Landmark`, a variable-stiffness `fill` case, unit-conversion cases (cm→mm, "3 degrees" vs "3°"), and at least two designed to trip `needs_manual=True` (contradictory / out-of-range / ambiguous). Keep `order_id` uniform (e.g. the case_id) since `parse_prescription` overwrites it authoritatively.

2. **Run modes.** `score_rx.py` takes `--offline` (default in CI) vs `--live`.
   - `--live`: **lazy-import the parser inside this branch only** — `from rx_parser import parse_prescription` at module top would pull `anthropic` (rx_parser.py L16 top-imports it) and break the offline path when the package is absent. Call `parse_prescription(case.rx_text, order_id=case.case_id)`; if `--write-fixtures`, dump `pred.model_dump_json(indent=2)` to `eval/fixtures/<case_id>.json`. Fixtures capture **real model output** from this live keyed run — **never seed them from `expected`** (that would make every case a trivial full pass and measure nothing). Fixtures may also be hand-authored from real model output, but not copied from the labels.
   - `--offline`: import **`schema` alone** (never `rx_parser`); load `eval/fixtures/<case_id>.json` via `Prescription.model_validate_json(path.read_text())`. Skip (don't fail) cases with no fixture, and report the count skipped. This path imports nothing from `anthropic` and needs no key.

3. **Field-level scoring** (per case, aggregated at the end). For each foot slot in `("left", "right")`:
   - **Side assignment:** compare `expected.<side> is None` vs `pred.<side> is None`. Tally a per-case boolean `side_ok`. A foot present-when-should-be-absent (or vice-versa) is a side error.
   - **Mod presence (precision/recall per type):** for a present foot, form multisets of `m.type` for expected vs predicted mods. Per mod type, accumulate TP/FP/FN across all cases → report precision/recall/F1 per type and micro-averaged.
   - **Param tolerance:** greedily match expected↔predicted mods of the same `type` (one-to-one). For each matched pair compare the type's numeric fields within tolerance and count `param_ok` / `param_total`. Fields by type (from schema): `MedialWedge`/`LateralWedge`→`degrees`; `HeelLift`→`height_mm`; `MetPad`→`height_mm`; `Relief`→`depth_mm`, `radius_mm`, plus exact-match on `landmark`. Default tolerances (tunable module constants): `DEG_TOL = 0.5`, `MM_TOL = 1.0`. Unit-conversion correctness is captured here (a cm-vs-mm miss shows up as a param-out-of-tolerance failure); tag those cases in the confusion list.
   - **`needs_manual` firing:** compare `expected.needs_manual` vs `pred.needs_manual`; accumulate a 2×2 (report `needs_manual` precision/recall/rate).
   - **Fill (light check):** when `expected.<side>.fill` is set, confirm `pred` fill is non-`None` and compare `family`/`density` per zone (`heel/midfoot/forefoot/toe`) within `DENSITY_TOL = 0.1`. Keep this a secondary metric; do not block on it.

   ```python
   # sketch — greedy same-type match, then per-field tolerance
   def match_mods(exp_mods, pred_mods):
       pred = list(pred_mods)
       for e in exp_mods:
           j = next((k for k,p in enumerate(pred) if p.type == e.type), None)
           yield e, (pred.pop(j) if j is not None else None)   # None => FN
       for p in pred:
           yield None, p                                        # leftover => FP
   ```

4. **Report.** Print a summary block (overall case pass-rate; per-mod-type P/R/F1; param-tolerance pass fraction; side-assignment accuracy; `needs_manual` P/R and fired-rate) and a **confusion list**: one line per failing case with `case_id`, the failing dimension(s), and expected-vs-got for the offending field. Exit non-zero if any hard dimension (side, mod-presence, `needs_manual`) regresses below a configurable `--min-*` threshold (default: informational, exit 0) so it can gate CI later.

5. **Tuning loop.** Use the confusion list to iterate on `SYSTEM_PROMPT` / add few-shots in `rx_parser.py` (that edit is a separate change, out of this module's scope), then re-run `--live --write-fixtures` to refresh fixtures and record the new numbers in `eval/README.md`.

**Backward-compat / guardrails**
- No change to `generate_orthotic`'s 6-tuple return `(solid, aligned, hf, top, mask, report)`, to `validate`'s report keys, or to any `schema.py` model — the harness only *reads* `Prescription`/`FootRx`/`Mod` fields.
- Do not alter `rx_parser.parse_prescription` behavior or signature here; the harness treats it as a black box.
- `run_demo.py` must still run unchanged (`python run_demo.py`, ~12s) — the new `eval/` package is not imported by the geometry pipeline or `app.py`.
- New deps: none required. Scoring is stdlib + Pydantic (already a dep). Do **not** pull in `pytest`/`numpy` for this; if a `pytest` wrapper is desired, make it optional and keep the plain `python -m eval.score_rx` path working. `--live` is the only path that imports `anthropic` (already a dep), and it must do so via the in-branch lazy import above; `--offline` must import zero new packages and must not import `rx_parser`.

**Acceptance criteria**
- **Offline, no key** (CI path): `unset ANTHROPIC_API_KEY && python -m eval.score_rx --offline` runs to completion using `eval/fixtures/`, prints the summary + confusion list, and exits 0. Confirm it imports nothing from `anthropic` (e.g. runs with the package absent) — because `--offline` never imports `rx_parser`.
- **Fixtures present:** every seed case in `eval/rx_dataset.py` has a matching `eval/fixtures/<case_id>.json` that `Prescription.model_validate_json` loads without error. Fixtures are generated as a **live/keyed one-shot** (`--live --write-fixtures`) or hand-authored from real model output, then committed — they are **never seeded from `expected`** (a fixture copied from the label would trivially full-pass and measure nothing).
- **Scoring correctness:** a deliberately-wrong fixture (e.g. swap a `HeelLift` height_mm beyond `MM_TOL`, or set `needs_manual` opposite) appears in the confusion list with the correct dimension flagged; a fixture equal to `expected` scores as a full pass. Include a tiny self-check (assert on a synthetic in-memory exp/pred pair — no fixture files, no model call) so scoring logic is CI-testable on its own; this synthetic self-check is the real offline-testable piece.
- **Live path (needs key, not run in CI):** `python -m eval.score_rx --live` calls `parse_prescription`, produces the same report shape, and `--write-fixtures` refreshes the JSON.
- **README numbers:** `eval/README.md` records the measured per-mod-type accuracy and `needs_manual` fired-rate from the latest `--live` run.

**Effort: M** — new self-contained package (dataset + greedy matcher + report + fixtures) with no core-code changes and no new dependencies; bulk of the work is authoring a representative seed set and the per-type scoring bookkeeping.

---

# 4. Pressure-based validation check

**Objective.** Add a deterministic plantar-pressure *estimate* (Winkler elastic-foundation spring-bed, not FEA) to the validation step in `geometry.py`, producing a per-cell pressure map (kPa) plus peak/mean/location metrics that feed the `report` dict and a heatmap preview. The local spring stiffness tracks the zone fill density, so softer lattice zones show measurably lower peak pressure.

**Why it matters.** A geometric "pass" is not clinical proof — a cheap pressure proxy makes validation meaningful and gives the review UI an offloading story competitors (Phits) don't surface.

**Files to touch.**
- `/Users/sam/Documents/Claude/Orthopipe/geometry.py` — new constants, new `estimate_pressure(...)` helper, wire into `generate_orthotic` (metrics merged onto `report` — **not** by changing `validate`'s signature).
- `/Users/sam/Documents/Claude/Orthopipe/run_demo.py` — write the pressure heatmap PNG next to existing previews (confirm in code how previews are currently rendered).
- No schema change: reuse the existing `Fill` / `ZoneFill` (`family`, `density` 0.0–1.0) and `FootRx.fill: Optional[Fill]` from `schema.py`.

**Prerequisite assumption.** Batch-1's lattice generator is described as landed, but the current `geometry.py` inventory shows lattice **ABSENT** (no `lattice.py`, not wired into `generate_orthotic`). Confirm this in code first. This item does **not** depend on a solid lattice mesh existing — it only needs a per-cell *relative-density field* ρ∈(0,1]. Derive ρ directly from `rx.fill` zone densities mapped onto the `Heightfield` grid (below). If `rx.fill is None`, ρ≡1 (solid) and the check still runs against a solid baseline.

**Exact approach.**

1. **Constants** (near `CELL_MM`/`MIN_THICKNESS_MM`, all tunable):
   ```python
   BODY_LOAD_N        = 350.0    # ~50% BW of a 70 kg subject, single-foot stance
   E_SOLID_PA         = 20.0e6   # nominal TPU-ish compressive modulus (tune vs bench)
   GIBSON_ASHBY_N     = 2.0      # bending-dominated lattice exponent: E_eff ≈ E_solid*ρ^n
   PRESSURE_PEAK_MAX_KPA = 600.0 # above this = implausible (clinical peaks ~200–500 kPa)
   ```

2. **Density field** `_density_field(hf, mask, rx) -> np.ndarray` (shape `(hf.ny, hf.nx)`):
   - start `rho = np.ones((hf.ny, hf.nx))`.
   - if `rx.fill` is set, map each `ZoneFill.density` onto rows by normalized length using `hf.yn()` (per-row normalized heel→toe length; confirm returned shape in code). Suggested yn bands (tunable, align with `apply_mods` conventions): `heel [0,0.25)`, `midfoot [0.25,0.55)`, `forefoot [0.55,0.85)`, `toe [0.85,1.0]`. Clamp `rho` to a small floor (e.g. `max(density, 0.05)`) to avoid zero stiffness.

3. **Pressure solve** `estimate_pressure(top, mask, hf, rx) -> tuple[np.ndarray, dict]` — receives the final modded `top` and `mask` (the same arrays `generate_orthotic` already holds at L443):
   - per-cell tributary area `A = (hf.cell/1000.0)**2` m² (`CELL_MM=2.0`).
   - local thickness `t_i = max(top_i, MIN_THICKNESS_MM)/1000.0` m; `E_eff_i = E_SOLID_PA * rho_i**GIBSON_ASHBY_N`; foundation modulus `k_i = E_eff_i / t_i` (Pa/m). Softer/thicker → lower `k_i`.
   - rigid-flat-indenter closure: `gap_i = top.max() - top_i` (m, over `mask`); penetration `δ_i(Δ) = max(Δ - gap_i, 0)`; solve scalar `Δ` s.t. `Σ_i k_i·A_i·δ_i(Δ) = BODY_LOAD_N` by 1-D bisection (total force is monotonic increasing in Δ). ~40 iterations is plenty and deterministic.
   - `p_i = k_i * δ_i(Δ)` Pa → `p_kpa = p_i/1000` (0 off-mask).
   - **solid baseline:** re-run the same solve with `rho≡1` to get `peak_solid_kpa` (this is the offloading reference).

4. **Metrics dict** (all NEW, additive):
   ```python
   {"peak_pressure_kpa": round(float(p_kpa.max()), 1),
    "mean_pressure_kpa": round(float(p_kpa[mask].mean()), 1),
    "peak_location": [int(r), int(c)],           # argmax row,col in hf grid
    "contact_area_cm2": round(mask.sum()*(hf.cell/10.0)**2, 1),
    "peak_pressure_solid_kpa": round(float(peak_solid_kpa), 1)}
   ```

5. **Wire in via `report.update()` — do NOT change `validate`'s signature.** `validate(mesh, hf)` currently ignores `hf`; leave its signature and its single call site untouched. `generate_orthotic` already holds `top`, `mask`, `hf`, and the foot's `rx` at that point, so compute pressure there: `p_kpa, metrics = estimate_pressure(top, mask, hf, rx)`, then `.update()` the `metrics` onto `report` alongside the existing L441-442 updates. Add two boolean checks into `report["checks"]` (merge them in after `validate` returns) and, if `report["pass"]` is derived from `checks`, recompute it as `report["pass"] = all(report["checks"].values())` so the new checks participate:
   - `"peak_pressure_plausible": metrics["peak_pressure_kpa"] <= PRESSURE_PEAK_MAX_KPA`
   - `"pressure_reduced_vs_solid": metrics["peak_pressure_kpa"] <= metrics["peak_pressure_solid_kpa"] + 1e-6` (true and trivially satisfied when `rx.fill is None`, since map == baseline).
   Keep thresholds lenient enough that the `run_demo.py` scan still yields `report["pass"] == True`.

6. **Heatmap preview.** In `run_demo.py`, render `p_kpa` (masked) as a PNG using whatever the existing preview step uses (confirm in code — the preview path is **matplotlib Agg**, so `plt.imshow(np.where(mask, p_kpa, np.nan), cmap="inferno")` with a kPa colorbar, then `fig.savefig(...)`). Do not add a new hard dependency solely for this — reuse the existing matplotlib preview toolchain.

7. **Future accuracy (do NOT implement now):** note in a comment that CalculiX (`ccx`, `*HYPERFOAM` contact) or FEniCSx is the heavier real-FEA upgrade path from this spring-bed proxy.

**Backward-compat / guardrails.**
- `generate_orthotic`'s 6-tuple return `(solid, aligned, hf, top, mask, report)` must stay exactly as-is.
- All existing `report` keys (`pass`, `checks`, `volume_cm3`, `extents_mm`, `est_print_mass_g_tpu`, plus the L441-442 `side`/`mods_applied`/`warnings`/`foot_length_mm`/`output`) and existing `checks` sub-keys must remain — pressure keys/checks are **additive only**.
- `validate`'s signature `validate(mesh, hf)` is **unchanged** — pressure metrics are merged onto `report` in `generate_orthotic`, not passed through `validate`.
- `report["pass"]` stays a boolean; tune thresholds so the default `run_demo.py` output still passes.
- No new required dependency: numpy/scipy/trimesh are already imported; the solve is pure numpy. Any plotting reuses the current preview path.
- Determinism: fixed iteration count, no RNG — same scan → same pressure numbers.

**Acceptance criteria** (no `ANTHROPIC_API_KEY` needed — geometry path only):
1. `source .venv/bin/activate && python run_demo.py` completes in ~12s, prints a `report` containing `peak_pressure_kpa`, `mean_pressure_kpa`, `peak_location`, `contact_area_cm2`, `peak_pressure_solid_kpa`, and `report["pass"] is True`; the peak ideally lands in a clinically plausible band (roughly 100–500 kPa). **This band is advisory, not a hard gate** — `E_SOLID_PA`/`BODY_LOAD_N` are first-pass guesses and the band may not hold on the first run; the only hard gate is the `peak_pressure_plausible` check (`<= PRESSURE_PEAK_MAX_KPA = 600`) that keeps `report["pass"]` True. If the peak falls outside 100–500, flag it and tune the constants rather than failing the item. A pressure-heatmap PNG is written next to the existing preview PNGs.
2. Lattice-coupling smoke test (pure Python, no API key), e.g.:
   ```python
   from schema import FootRx, Fill, ZoneFill
   # solid vs softer heel (density 0.3)
   rx_soft = FootRx(fill=Fill(heel=ZoneFill(family="gyroid", density=0.3)))
   ```
   Run `estimate_pressure` on the same `top/mask/hf` with `rx.fill=None` vs `rx_soft`; assert the softer-heel peak `<` solid-baseline peak (offloading works and the map responds to the fill field).
3. Existing keys regression: assert `set(prior_report_keys).issubset(new_report.keys())` and every original `checks` sub-key still present.

**Effort: M** — one self-contained numpy solver plus a small heightfield→density mapping and a preview hook; the only ambiguity is reusing `run_demo.py`'s existing matplotlib preview rendering and confirming `hf.yn()`'s shape.

---

# 5. Local-LLM fallback for the Rx parser (PHI de-risk)

**Objective.** Refactor `rx_parser.parse_prescription` into a pluggable-backend function so the same validated `Prescription` can be produced either by the current Anthropic `messages.parse` path (default) or by a fully local model (Ollama or llama.cpp) selected via an env var, keeping the Pydantic schema as the single contract.

**Why it matters.** Prescription free-text can carry PHI; a local backend removes the one hard cloud dependency and lets a clinic run without a BAA.

**Files to touch.**
- `/Users/sam/Documents/Claude/Orthopipe/rx_parser.py` — extract the backend seam; add dispatcher.
- `/Users/sam/Documents/Claude/Orthopipe/rx_backends.py` — **NEW**: backend implementations (Anthropic default + local).
- `/Users/sam/Documents/Claude/Orthopipe/docs/rx-backends.md` — **NEW**: backend selection + Anthropic BAA path.
- `/Users/sam/Documents/Claude/Orthopipe/requirements.txt` — do **not** add `ollama`/`llama-cpp-python` as hard deps; note them as optional extras only.
- Rx eval harness from item 3 — **confirm in code** (inventory shows `eval` modules ABSENT; assume item 3 lands an eval entrypoint that already imports `parse_prescription`. If absent, the spec below still stands — the new `backend=` kwarg is additive and the harness parametrizes over it).

**Exact approach.**

1. **Define the seam.** In `rx_backends.py`, extract everything currently between client construction and the `order_id` override (rx_parser.py L58–71) behind a uniform signature. Keep `MODEL` (L20, `"claude-opus-4-8"`) and `SYSTEM_PROMPT` (L22–49) in `rx_parser.py` and pass them in:
   ```python
   # rx_backends.py
   def anthropic_backend(system: str, user: str, output_format) -> Prescription: ...
   def local_backend(system: str, user: str, output_format) -> Prescription: ...
   ```
   Each returns a validated `Prescription`. The `rx.order_id = order_id` override (L72) stays in `parse_prescription`, outside the backend.

2. **Anthropic backend = current behavior verbatim.** Move the L58–68 block in: `anthropic.Anthropic()`, `client.messages.parse(model=MODEL, max_tokens=16000, system=system, messages=[{"role":"user","content":user}], output_format=output_format)`, the `stop_reason == "refusal"` → `RuntimeError` check, and `response.parsed_output`. This path is byte-for-byte what runs today.

3. **Local backend = JSON-schema-constrained decode, then manual validate.** A local model has no `messages.parse` equivalent, so:
   - Derive schema from Pydantic: `output_format.model_json_schema()`.
   - **Ollama** (default local impl): `from ollama import chat`; `resp = chat(model=os.environ.get("ORTHOPIPE_RX_LOCAL_MODEL", "llama3.1"), messages=[{"role":"system","content":system},{"role":"user","content":user}], format=output_format.model_json_schema(), options={"temperature": 0})`; then `output_format.model_validate_json(resp.message.content)`.
   - **llama.cpp** alternative (confirm which to ship; Ollama is the lighter default): `LlamaGrammar.from_json_schema(...)` passed as `grammar=` to `create_chat_completion`, or llama-server `response_format={"type":"json_schema", ...}`. Because the schema constrains tokens but is not shown to the model, keep `SYSTEM_PROMPT` (which already describes structure, mods, fill families/zones) as the prompt — it stays provider-agnostic.
   - Import the local client **lazily inside the function** so importing `rx_parser` never requires `ollama`/`llama-cpp-python`.

4. **Dispatcher + env var.** Add an optional `backend: str | None = None` kwarg to `parse_prescription(rx_text, order_id="ORDER", backend=None)` so the eval harness can force a path; when `None`, read the env var. Then select before calling, **raising `ValueError` on an unknown name** (bare dict indexing would raise `KeyError`, but acceptance requires `ValueError`):
   ```python
   _BACKENDS = {"anthropic": anthropic_backend, "local": local_backend}
   name = backend or os.environ.get("ORTHOPIPE_RX_BACKEND", "anthropic")
   if name not in _BACKENDS:
       raise ValueError(f"unknown ORTHOPIPE_RX_BACKEND={name!r}; expected one of {sorted(_BACKENDS)}")
   backend_fn = _BACKENDS[name]
   ```
   Default resolves to `"anthropic"` — unchanged behavior.

5. **Fail loud, never silent-fallback.** If the selected backend name is unknown → `ValueError` (per step 4). If `"local"` is selected but the client import fails or the server isn't reachable → raise `RuntimeError` with a clear message (`"ORTHOPIPE_RX_BACKEND=local requires the 'ollama' package and a running Ollama server"`). Do **not** fall back to Anthropic.

6. **Docs.** In `docs/rx-backends.md`: (a) env-var selection table; (b) the BAA fact — for PHI on the cloud path you must be on the Messages API under a signed Anthropic BAA (Console/Workbench and Pro/Team are not covered; Covered Models require 30-day retention, so ZDR is not available for them); (c) the local path as the PHI-safe default with no data leaving the machine.

7. **Eval harness extension.** Parametrize the item-3 Rx eval over `backend in ("anthropic","local")` via the new kwarg (**confirm harness entrypoint in code**). Skip the `anthropic` case when `ANTHROPIC_API_KEY` is unset; skip the `local` case when Ollama is unreachable — so CI can run whichever is available.

**Backward-compat / guardrails.**
- `parse_prescription(rx_text, order_id="ORDER")` signature stays call-compatible (new kwarg is optional, defaults preserve today's behavior); `app.py` `/api/parse_rx` (`parse_prescription(...)` → `rx.model_dump()`) is untouched.
- Default env (unset `ORTHOPIPE_RX_BACKEND`) must reproduce the exact current Anthropic path, including the `order_id` override and refusal check.
- `geometry.py` is not touched: `generate_orthotic`'s 6-tuple return `(solid, aligned, hf, top, mask, report)` and `validate`'s report keys (`pass`, `checks`, `volume_cm3`, `extents_mm`, `est_print_mass_g_tpu`) are out of scope and must not change.
- `run_demo.py` (geometry-only, no parser) must still pass unchanged.
- No new **hard** deps: `ollama`/`llama-cpp-python` stay optional/lazy-imported; `requirements.txt` core install must still succeed without them.

**Acceptance criteria.**
- `ORTHOPIPE_RX_BACKEND` unset, with `ANTHROPIC_API_KEY` set: `python -c "from rx_parser import parse_prescription; print(parse_prescription('4mm medial wedge left', 'ORD1').order_id)"` prints `ORD1` (unchanged path).
- **No API key needed:** unknown backend fails fast — `ORTHOPIPE_RX_BACKEND=bogus python -c "from rx_parser import parse_prescription; parse_prescription('x')"` raises `ValueError` (not a network call, not a `KeyError`).
- **No API key needed:** `python -c "import rx_parser"` succeeds with `ollama`/`llama-cpp-python` **not** installed (proves lazy import / light default).
- **No API key needed:** `ORTHOPIPE_RX_BACKEND=local` with no Ollama running raises a clear `RuntimeError` mentioning `local` and the missing dependency/server — and never contacts Anthropic (confirm no `anthropic.Anthropic()` construction on this path).
- With Ollama running locally: `ORTHOPIPE_RX_BACKEND=local python -c "from rx_parser import parse_prescription; p=parse_prescription('softer heel, 4mm medial wedge, left foot','ORD2'); print(p.order_id, bool(p.left))"` returns a validated `Prescription` (`p.order_id == "ORD2"`) with no network egress.
- `python run_demo.py` still emits STLs + preview PNGs (~12s), unaffected.
- Eval harness runs green over both backends, auto-skipping whichever is unavailable.

**Effort: M** — small, well-isolated refactor (one seam + dispatcher + docs), but a second inference path and its eval coverage add real surface to get right.

---

# 6. Phone-scan-only intake path

**Objective.** Let a clinician upload a phone-captured mesh (TrueDepth/LiDAR export) through the *existing* `/api/upload` → `/api/generate` flow, adding a format-normalization helper (usdz/ply → obj) and a units/scale sanity check (meters-vs-mm), plus a neutral-position capture prompt in the review UI.

**Why it matters.** Removes the scanner-hardware lock-in and lowers the barrier for the small clinics OrthoPipe wins first — a phone + a neutral-position guide is the entire capture rig.

**Product/GTM item — independent of all calibration/engine work. It rides entirely on the current `.obj/.stl/.ply` upload path and needs no changes to `generate_orthotic`.**

**Files to touch**
- `app.py` — extend `/api/upload` accepted extensions; call normalization + scale-check before storing in `SCANS`.
- `intake.py` — **NEW** — normalization + units helpers (keep it a small standalone module; no geometry-engine coupling).
- `static/index.html` **and** root `index.html` — add the capture-guidance prompt near the upload control (CLAUDE.md says keep both in sync).
- `requirements.txt` — only if the optional usd-core path is adopted (see guardrails).

**Exact approach**

1. **Widen accepted formats at upload.** `/api/upload` (app.py L38-47) currently gates on `file.filename.lower().endswith((".obj",".stl",".ply"))`. Add `.usdz` to that tuple and update the 400 message string. `.obj/.stl/.ply` already load natively in `trimesh` per the inventory — no conversion needed for those; only `.usdz` requires tooling.

2. **New `intake.py` — `normalize_scan(path: str) -> tuple[str, list[str]]`.** Returns `(obj_or_native_path, warnings)`. Logic:
   - `.obj/.stl/.ply` → return the path unchanged (trimesh loads these directly; `generate_orthotic` already does `trimesh.load(scan_path, force="mesh")`).
   - `.usdz` → attempt conversion to `.obj` via `usd-core` (`from pxr import Usd, UsdGeom`): open the stage, traverse `UsdGeom.Mesh` prims, read `points` + `faceVertexIndices`, build `trimesh.Trimesh(vertices, faces)`, `.export(<same_stem>.obj)`, return the new path. **Degrade gracefully:** wrap the `pxr` import in try/except; if usd-core is absent, append a warning like `"usdz upload received but USD tooling not installed — export .obj/.ply from the capture app"` and raise a clean `ValueError` the endpoint maps to HTTP 400. Do NOT hard-crash. (Confirm the exact usdz triangulation handling in code — `faceVertexCounts` may include quads/ngons that need fan-triangulation before building the Trimesh.)

3. **New `intake.py` — `check_and_fix_scale(mesh: trimesh.Trimesh) -> tuple[trimesh.Trimesh, list[str]]`.** Phone captures are sometimes in meters. Heuristic on `mesh.extents` (an `(x,y,z)` array; foot length is the long axis ≈ y):
   ```
   long = max(mesh.extents)
   if long < 1.0:          # a real foot is never < 1 unit if mm; ~0.12–0.36 if meters
       mesh.apply_scale(1000.0)
       warnings.append("scan appears to be in meters; auto-scaled ×1000 to mm")
   elif long < 40:         # ambiguous small — warn, don't touch
       warnings.append(f"scan long-axis {long:.1f} — below plausible foot length; check units")
   ```
   Anchor the mm thresholds to `validate`'s own plausibility band (`length_plausible: 120 <= ext[1] <= 360`, geometry.py L408) so a scaled scan lands inside it. Prefer running the scale check on the loaded mesh and re-exporting, OR expose it so it runs pre-`generate_orthotic`; the geometry engine re-floors/re-orients in `align_canonical`, so scaling must happen *before* the heightfield is built. Simplest wiring: do scale-check inside `normalize_scan` after load and re-export the corrected mesh.

4. **Wire into `/api/upload` only.** After saving raw bytes to `UPLOADS / f"{scan_id}_{file.filename}"`, call `normalize_scan(...)`; store the *returned* path (possibly the converted/rescaled `.obj`) plus the merged warnings into the `SCANS` dict alongside the existing `{path, filename, uploaded_at}`. `/api/generate` (L80-110) looks up `scan["path"]` and needs **no change** — it just receives an already-normalized `.obj`. Surface `warnings` in the `/api/upload` JSON response (add a `"warnings"` key alongside `{"scan_id","filename"}`) so the UI can show them.

5. **UI capture guidance.** In both `index.html` files, near the file-input control, add static instructional copy: neutral subtalar position (foot relaxed, ankle neutral, non-weight-bearing per clinic protocol), even lighting, slow orbit, and **"export .obj or .ply from your capture app"** as the recommended formats (usdz supported only if USD tooling is present server-side). No JS logic required beyond optionally rendering the new `warnings` array from the upload response. (Confirm exact upload-control markup/IDs in code.)

**Backward-compat / guardrails**
- **Do NOT touch `geometry.py`.** `generate_orthotic`'s 6-tuple return `(solid, aligned, hf, top, mask, report)` and `validate`'s report keys (`pass`, `checks`, `volume_cm3`, `extents_mm`, `est_print_mass_g_tpu`, plus the `.update()`-ed `side/mods_applied/warnings/foot_length_mm/output`) are unchanged — this feature ends at the upload boundary.
- **`run_demo.py` must still pass** (`.obj` path, no upload involved) — it never calls `intake.py`, so it is unaffected; verify it still runs in ~12s.
- **Existing `.obj/.stl/.ply` uploads must behave identically** — `normalize_scan` returns those paths untouched (aside from the meters heuristic, which only fires on sub-mm-scale extents).
- **New dep is optional.** `usd-core` is heavyweight; make the `pxr` import lazy/optional so the whole app installs and runs without it, and only `.usdz` uploads fail (gracefully, with the warning above). Do not add it to the default `requirements.txt` unless the team commits to server-side usdz — document it as an optional extra. `trimesh`/`numpy` are already deps.
- Keep the endpoint's existing "no size limit / no mesh validation at upload" posture unless explicitly asked — real validation stays in the geometry engine.

**Acceptance criteria**
- **No API key needed for any of this** (parser/`ANTHROPIC_API_KEY` is untouched).
- `python run_demo.py` still completes (~12s) and writes STLs + preview PNGs — proves geometry path unregressed.
- Unit-level, no server: `python -c "import trimesh, intake; m=trimesh.load('uploads/97ffe523_sample_scan_right.obj', force='mesh'); m2,w=intake.check_and_fix_scale(m); print(m2.extents, w)"` → prints extents already in mm (long axis in the ~120–360 band) with an **empty** warnings list (the sample is already mm).
- Meters case: scale the sample by 0.001, run `check_and_fix_scale`, expect a `×1000` warning and extents back in the plausible band.
- `.usdz` without usd-core: `POST /api/upload` a `.usdz` → HTTP 400 with the "export .obj/.ply" guidance, and the server does not crash (other endpoints still respond). Start server per CLAUDE.md: `python app.py`.
- `.obj` upload still returns `{"scan_id","filename", ...}` and a subsequent `/api/generate` produces a valid `report` — confirm the phone-intake plumbing is transparent to the happy path.
- Both `index.html` files show the neutral-position capture prompt (grep both for the guidance string).

**Effort: S** — one small new module (two helpers) + a one-line extension to `/api/upload` + static UI copy; the only real risk is the optional usdz/usd-core branch, which is isolated and degrades to a 400.

---

# Definition of done (global checklist)

- [ ] For **every** item completed: `source .venv/bin/activate && python run_demo.py` runs in ~12s and prints `report["pass"] is True` — no regressions to STL/preview outputs.
- [ ] `generate_orthotic`'s 6-tuple return `(solid, aligned, hf, top, mask, report)` and signature are byte-for-byte unchanged.
- [ ] `validate`'s report keys (`pass`, `checks`, `volume_cm3`, `extents_mm`, `est_print_mass_g_tpu`) and existing `checks` sub-keys are all still present; any new keys/checks are **additive only** (item 4), and `validate`'s own signature is unchanged.
- [ ] No new **hard** dependency: `requirements.txt` core install still succeeds; every added dep (ML libs, `ollama`/`llama-cpp-python`, `usd-core`) is optional, lazy-imported, and degrades gracefully when absent. (`rtree`/`manifold3d` are already hard deps, so item 1's signed-distance path needs nothing new.)
- [ ] Every new module imports cleanly with **no `ANTHROPIC_API_KEY`** and with optional deps absent (`import landmarks`, `import rx_parser`, `import intake`, `python -m eval.score_rx --offline`, `python replay.py --synthetic N`). In particular, `--offline` eval never imports `rx_parser`/`anthropic`.
- [ ] De-identification holds: no patient-identifying keys are ever written to any scorecard/summary/audit/output file (item 1).
- [ ] Batch-1 dependencies were **verified in code** before building on them; where incomplete, the code implements against current reality with an inline note on the assumption made.
- [ ] Each item's own acceptance criteria pass (see per-section lists).
- [ ] `app.py` existing endpoints, in-memory `SCANS`/`RESULTS`, response shapes, and audit write are untouched except for the explicitly-additive read endpoint (item 1) and the widened `/api/upload` extensions + `warnings` key (item 6).
- [ ] Changes are minimal and scoped — no unrelated refactors; code style matches the existing repo.

---

# Not a code task (one remaining research item)

**Regulatory classification — confirm before any market claims.** Determine the exact **FDA product code / device classification** for OrthoPipe's output (custom foot orthoses / the software as a medical device question) with a **qualified regulatory consultant**. This is a regulatory/legal research item, **not** an implementation task — do not attempt to encode a classification, add compliance claims to the UI, or make marketing/regulatory assertions in code or docs until this is confirmed by a professional.

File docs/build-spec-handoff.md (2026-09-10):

# OrthoPipe — Implementation Handoff

## You are working on

**OrthoPipe** is a pipeline that turns a 3D foot scan (`.obj`) plus a clinician prescription into a validated, 3D-print-ready orthotic STL. Stack: **Python, trimesh, pymeshlab, pydantic, FastAPI**.

Key files:
- `schema.py` — Pydantic Rx contract (the LLM↔geometry interface).
- `geometry.py` — the pipeline: cleanup → align → heightfield → shell → mods → validate → export.
- `rx_parser.py` — Claude-powered free-text Rx → `Prescription`.
- `app.py` — FastAPI review UI + audit log.

Dev setup:
```bash
source .venv/bin/activate
python run_demo.py   # end-to-end integration check (~12s) — MUST keep passing
python app.py        # serves UI on :8000; also copies index.html -> static/index.html
```

## How to work

- Make the **smallest change** that satisfies each spec. Do not refactor unrelated code.
- **Preserve public signatures and return shapes** unless a spec explicitly says to change them. In particular, `generate_orthotic` must keep its 6-tuple return `(solid, aligned, hf, top, mask, report)`.
- After each item, run `python run_demo.py` and confirm the validation report still passes (`watertight`, `positive_volume`, plausible dims; `report["pass"] == True`) **before moving on**.
- Match existing code style.
- If you introduce a dependency, add it to `requirements.txt` (and confirm it installs on the 3.11 `.venv`).
- **Ask nothing** — implement to the spec. Where the spec says "confirm in code," verify against the actual source and note any assumption inline as a comment.

## Sequencing

Items **1–2** unblock real scan data; items **3–4** build the variable-stiffness lattice (the product differentiator); item **5** hardens the regulatory record. Do them in order — they are mostly independent, with the one hard dependency being that **item 4 consumes item 3's schema**.

---

## 1. Wire PyMeshLab mesh repair into `clean_scan`

**Objective.** Replace the trimesh-only `clean_scan` stub in `geometry.py` with a real PyMeshLab `MeshSet` repair recipe (dedup → close holes → optional quadric decimation → light Taubin smoothing) that runs before `align_canonical`, so hole-riddled real scanner exports become watertight-ish, print-ready input. Keep the signature and return type intact; make heavy repair skippable for the synthetic-foot path; surface every substantive action as a warning rather than a silent guess.

**Why.** Real scanner exports are hole-riddled — this is the #1 blocker to real de-identified scan data. `pymeshlab` is already a declared dependency but unused.

**Files.** `geometry.py` only — rewrite `clean_scan` (currently L29-41) and adjust its call site in `generate_orthotic` (L295, `scan = clean_scan(scan)`). No new files. `requirements.txt` already lists `pymeshlab` — confirm; do not re-add.

**Approach.**
1. **Import.** First verify the wheel is actually installed in the `.venv` (`pip show pymeshlab`) — CLAUDE.md declares it, but the venv may lack the wheel. If it is installed, add `import pymeshlab` at the top alongside `numpy`/`trimesh` (Python 3.10+ is required precisely because of it). **If you cannot confirm it is installed, do NOT add a top-level hard import** — a missing wheel makes `geometry.py` unimportable and takes down both `run_demo.py` **and** `app.py` at import time, a regression from today (geometry.py currently imports cleanly with pymeshlab unused). In that case keep the import **local to `clean_scan`** and raise a clear error if heavy repair is requested without the wheel.
2. **Extend the signature without breaking callers:**
   ```python
   def clean_scan(
       mesh: trimesh.Trimesh,
       heavy_repair: bool = True,
       target_faces: int | None = 80000,
       warnings: list[str] | None = None,
   ) -> trimesh.Trimesh:
   ```
   Return type stays `trimesh.Trimesh`. `heavy_repair=False` is the synthetic-foot escape hatch (skip close-holes + decimation, keep cheap dedup + smoothing). If `warnings is None`, create a local list so behavior is unchanged when omitted.
3. **Keep existing trimesh pre-steps as a fast guard.** Retain the largest-component split (`mesh.split(only_watertight=False)`, keep max `.area` component if >1 part) and `mesh.update_faces(mesh.nondegenerate_faces())` / `remove_unreferenced_vertices()` before handing to PyMeshLab — this drops junk that would skew PCA in `align_canonical`. Warn if >1 component was discarded.
4. **Round-trip trimesh → `MeshSet` → trimesh, in memory (no temp file):**
   ```python
   ms = pymeshlab.MeshSet()
   ms.add_mesh(pymeshlab.Mesh(vertex_matrix=mesh.vertices, face_matrix=mesh.faces))
   ```
   Confirm the constructor kwarg names in code; if the in-memory constructor is problematic, fall back to `ms.load_new_mesh(path)` on a temp `.ply` in the scratchpad + `ms.save_current_mesh(...)`. `ms.current_mesh()` exposes `.vertex_matrix()` / `.face_matrix()`.
5. **Repair recipe (current PyMeshLab filter names — pre-2022.2 names are deprecated):**
   - Dedup/cleanup: `meshing_remove_duplicate_vertices()`, `meshing_remove_duplicate_faces()`, `meshing_remove_unreferenced_vertices()`, `meshing_remove_null_faces()`.
   - Close holes: `ms.meshing_close_holes(maxholesize=40)` (note the chosen value in a comment). Optionally `meshing_repair_non_manifold_edges()` first if hole-filling fails on non-manifold input.
   - **Decimation, gated on `heavy_repair and target_faces` and only if over budget:**
     ```python
     if heavy_repair and target_faces and ms.current_mesh().face_number() > target_faces:
         ms.meshing_decimation_quadric_edge_collapse(
             targetfacenum=target_faces, preservenormal=True, planarquadric=True)
     ```
   - Light Taubin smoothing: `ms.apply_coord_taubin_smoothing(stepsmoothnum=10)` (keep `lambda_`≈0.5, `mu`≈-0.53 comparable to the old `filter_taubin(lamb=0.5, nu=-0.53, iterations=6)`). Note `lambda_` has a trailing underscore.
   - When `heavy_repair=False`: run only dedup + Taubin; skip close-holes and decimation.
6. **Rebuild + preserve invariants.** Return `trimesh.Trimesh(vertices=ms.current_mesh().vertex_matrix(), faces=ms.current_mesh().face_matrix(), process=True)`. Do **not** re-floor, re-scale, or re-orient — orientation, mirroring, and the plantar `z=0` floor belong to `align_canonical` (L57-112). `clean_scan` stays a pure repair pass.
7. **Warnings, not silent guesses.** Replace the current `try/except BaseException: pass`. On each substantive action or failure, append to `warnings`, e.g. `"clean_scan: closed N holes (maxholesize=40)"`, `"clean_scan: decimated 210k->80k faces"`, `"clean_scan: discarded 3 stray components"`, or `"clean_scan: meshing_close_holes failed (<err>); proceeding with unrepaired mesh"`. Use before/after `face_number()` / `vertex_number()` counts.
8. **Thread warnings through `generate_orthotic` (L293-309):**
   ```python
   warnings = []
   scan = clean_scan(scan, warnings=warnings)
   aligned, align_warnings = align_canonical(scan, side)
   warnings += align_warnings
   ```
   Keep the final `report.update({... "warnings": warnings ...})` merge and the 6-tuple return unchanged.
9. **Synthetic path.** `synthetic_foot.py` produces clean watertight meshes. Where the synthetic/demo flow cleans a mesh, pass `heavy_repair=False`. Confirm whether `run_demo.py`/`synthetic_foot.py` call `clean_scan` directly or only via `generate_orthotic`; if only via `generate_orthotic`, prefer the smallest change (an optional pass-through) that lets synthetic meshes skip close-holes/decimation. Leaving heavy repair on is safe (cheap on clean meshes) if a pass-through would bloat the change.

**Guardrails.** `clean_scan(mesh)` still works and returns one `trimesh.Trimesh`; new params are keyword defaults. `generate_orthotic`'s 6-tuple return is unchanged (`app.py` L96-98 unpacks `_, _, _, _, _, report`). No reorientation/mirroring/z-flooring in `clean_scan`. `MIN_THICKNESS_MM=2.0` clamps (L224/L226), the watertight solid build (L232-271), and `validate`'s checks (L276-288) must still pass on synthetic input. `run_demo.py` stays non-interactive (~12s). Report keys `side`, `mods_applied`, `warnings`, `foot_length_mm`, `output` preserved (additive only).

**Acceptance.**
1. `python -c "import pymeshlab; print(pymeshlab.__version__)"` succeeds.
2. `python run_demo.py` completes (~12s), writes STL(s) + preview PNG(s), `report["pass"] is True` with `checks.watertight` and `positive_volume` both True; synthetic path shows no spurious `clean_scan: closed ... holes` warnings.
3. **Holey-mesh check:** puncture a synthetic mesh (delete a face patch), run `clean_scan(mesh, heavy_repair=True, warnings=w)`; assert higher `is_watertight` / fewer boundary edges than input and a `clean_scan: closed ... holes` entry in `w`. Throwaway scratchpad script is fine — don't commit it or any generated output.
4. **Decimation budget:** input > `target_faces` → returned faces ≤ `target_faces` and a decimation warning; input under budget → no decimation, no warning.
5. **Skip path:** `clean_scan(mesh, heavy_repair=False)` calls neither close-holes nor decimation (verify by absent warnings) and returns a valid mesh.
6. **Regression:** `python app.py` starts; `/api/generate` on a synthetic scan returns `report` with `pass: True`.

**Effort: M.**

---

## 2. Add ICP-based scan alignment (adapt ampscan)

**Objective.** Add an iterative-closest-point (ICP) registration path that aligns a cleaned scan to a canonical template frame, used as a refinement on top of the PCA `align_canonical`. Vendor a minimal, MIT-attributed copy of ampscan's ICP rather than depending on the dormant PyPI package, and surface the alignment residual into the report warnings when it exceeds a threshold.

**Why.** PCA canonical alignment is brittle on real feet; ICP registration to a template is far more robust — and ampscan is MIT, so vendor the relevant module rather than depend on dormant releases.

**Files.**
- `geometry.py` — add ICP path; wire into `align_canonical`.
- `vendor/ampscan_icp.py` — **NEW.** Minimal vendored ICP (point-to-plane SVD + point-to-point), MIT header preserved, attributed to `github.com/abel-research/ampscan`.
- `vendor/__init__.py` — **NEW** (empty).
- `vendor/LICENSE.ampscan` — **NEW.** Verbatim ampscan MIT license text (copy exact text from upstream at vendor time).
- `templates/right_foot_template.stl` (or `.obj`) — **NEW.** Canonical right-foot template that MUST be in the internal frame (RIGHT-foot convention, +Y heel→toe, +X medial, +Z up, plantar min z=0, mm). If no real asset exists, generate one from `synthetic_foot.py` **and pass it through `align_canonical` (side="right") before checking it in** — raw `synthetic_foot.py` output is NOT guaranteed to be in the canonical frame, and ICP-registering real scans against a mis-framed template silently mis-aligns every part. Verify the checked-in mesh is in-frame (plantar min z≈0, correct axes) before committing. **Confirm the generator + `align_canonical` API in code.**
- `CLAUDE.md` — add one line to the Layout table for `vendor/` and `templates/`.

Do **not** add `ampscan` to `requirements.txt`.

**Approach.**
1. **Vendor the ICP core** in `vendor/ampscan_icp.py`: the rigid-registration math from ampscan's `align` class (`runICP`, `linPoint2Plane`, `linPoint2Point`, `getRMSE`, `getRT`). Strip the `AmpObject` dependency — operate on plain numpy arrays. Preserve the MIT header. Target:
   ```python
   # vendor/ampscan_icp.py  (adapted from ampscan, MIT — abel-research/ampscan)
   def register_icp(moving_v, moving_f, static_v, static_f,
                    method="linPoint2Plane", maxiter=20, inlier=1.0):
       """Returns (T 4x4 homogeneous, rmse float)."""
   ```
   Keep the `method` strings and `inlier` (0–1 proportion of nearest points) / `maxiter` semantics. Import only numpy/scipy/trimesh (already in use).
2. **Load/cache the template once.** In `geometry.py`, lazily `trimesh.load(..., force="mesh")` the template with a module-level cache so `run_demo.py`'s budget isn't hurt.
3. **Refinement function:**
   ```python
   ICP_RESIDUAL_WARN_MM = 3.0   # near CELL_MM (L23) / MIN_THICKNESS_MM (L24)

   def refine_icp(mesh, template) -> tuple[trimesh.Trimesh, float]:
       T, rmse = register_icp(mesh.vertices, mesh.faces, template.vertices, template.faces)
       out = mesh.copy(); out.apply_transform(T)
       return out, rmse
   ```
4. **PCA initializes, ICP refines.** Keep `align_canonical(mesh, side) -> (mesh, warnings)` (L57) as the initializer (it already mirrors left feet into the right convention, L61-63). **Prefer** running ICP against the right-foot template **inside `align_canonical`, before the origin re-zeroing (L109-111)**, so origin normalization runs last and downstream code is untouched.
5. **Gate + fall back to PCA.** If the ICP residual is worse than PCA-only, or `register_icp` raises, keep the PCA result. Append to the existing `warnings`:
   ```python
   if rmse > ICP_RESIDUAL_WARN_MM:
       warnings.append(f"ICP alignment residual {rmse:.1f}mm exceeds {ICP_RESIDUAL_WARN_MM}mm; flag for reviewer")
   ```
   This rides existing plumbing — no API changes.
6. **Optional feature flag:** `align_canonical(mesh, side, use_icp: bool = True)`, keyword-with-default so positional callers (`generate_orthotic` L295) still work.

**Guardrails.** `generate_orthotic` 6-tuple unchanged. `align_canonical` return type `(trimesh.Trimesh, list[str])` unchanged; ICP output stays a single connected mesh in the canonical frame with plantar floor z=0 (`Heightfield.__init__` L120 still works). Left-foot handling unchanged (mirror-back about X at L302, `volume<0` invert at L304). Don't touch `build_shell`/`apply_mods`/`solid_from_heightfield`/`validate` or the `MIN_THICKNESS_MM` clamps. No new hard dependency. Missing template → degrade gracefully to PCA, never crash. Preserve MIT text/attribution.

**Acceptance.**
- `python run_demo.py` completes, still emits STLs + PNGs, roughly same time.
- Report still shows `watertight=True`, `positive_volume=True`, plausible dims, `pass=True`.
- `report["warnings"]` present; a well-aligned demo scan has **no** ICP residual warning, but a perturbed input (or lowered `ICP_RESIDUAL_WARN_MM`) makes the `"ICP alignment residual ... exceeds ..."` warning appear.
- Since `align_canonical` returns `(mesh, warnings)` (no `rmse` in its signature), assert on the residual **warning** rather than a returned number: a misaligned input crosses `ICP_RESIDUAL_WARN_MM` and produces the `"ICP alignment residual ... exceeds ..."` entry in `report["warnings"]`, while a well-aligned input does not. (If you want a raw-number check that `rmse` decreases, print it from a direct `refine_icp`/`register_icp` call in a throwaway scratchpad script — not via `align_canonical`.)
- Left and right sides both produce correct-chirality output.
- `python -c "from vendor.ampscan_icp import register_icp"` imports with no `ampscan` installed.
- `grep -i "MIT" vendor/ampscan_icp.py` and presence of `vendor/LICENSE.ampscan` confirm attribution.

**Effort: M.**

---

## 3. Add optional per-zone lattice/fill to the Rx schema (defaults to solid)

**Objective.** Extend the Pydantic Rx contract in `schema.py` with an *optional* per-zone lattice/fill spec, and teach the `rx_parser.py` system prompt to emit it only on explicit variable-stiffness requests. **No geometry** — ship the validated contract plus documented default constants (zone→lattice map). Omitting fill must reproduce today's solid part identically.

**Why.** Lets the prescription drive per-zone stiffness (the differentiator) while staying 100% backward-compatible.

**Files.** `schema.py` (add fill models + constants) and `rx_parser.py` (extend `SYSTEM_PROMPT`, L22-41). No new files. Do **not** touch `geometry.py`, `app.py`, or `static/index.html`.

**Approach.**
1. **Enums** (reuse the `Literal`-alias style of `Landmark` on L8):
   ```python
   LatticeFamily = Literal["solid", "gyroid", "diamond", "primitive"]
   Zone = Literal["heel", "midfoot", "forefoot", "toe"]
   ```
   These anatomical zone names are **new** and distinct from the existing `Landmark` literals (`base_5th_met`, `met_heads`, `heel_center`, `arch_apex`, `hallux`). Keep both; do not merge or rename `Landmark`.
2. **`ZoneFill` model** (mirror the `Field(default, ge=, le=)` convention of `MedialWedge`/`Relief`):
   ```python
   class ZoneFill(BaseModel):
       family: LatticeFamily = "solid"
       density: float = Field(1.0, ge=0.0, le=1.0)   # 1.0 == fully solid
   ```
3. **Top-level `Fill` container**, per-zone (FootRx-level path — keeps fill out of the fixed-order `mods` pipeline and doesn't touch the `Mod` union):
   ```python
   class Fill(BaseModel):
       heel: ZoneFill = Field(default_factory=ZoneFill)
       midfoot: ZoneFill = Field(default_factory=ZoneFill)
       forefoot: ZoneFill = Field(default_factory=ZoneFill)
       toe: ZoneFill = Field(default_factory=ZoneFill)
   ```
   Use `default_factory` to avoid shared-instance aliasing. **Confirm Pydantic v2 is in use** (the union on L38 and `messages.parse(output_format=...)` in `rx_parser.py` both imply v2).
4. **Attach `Fill` as OPTIONAL on `FootRx`** (L41-42), default `None`:
   ```python
   class FootRx(BaseModel):
       mods: List[Mod] = []
       fill: Optional[Fill] = None   # None => solid everywhere (current behavior)
   ```
   `Optional` is already imported. Old `{"mods":[...]}` JSON still validates.
5. **Documented default zone→lattice map** (data only): Primitive=heel, Gyroid=forefoot, Diamond=toe+midfoot:
   ```python
   DEFAULT_ZONE_LATTICE: dict[str, str] = {
       "heel": "primitive", "midfoot": "diamond",
       "forefoot": "gyroid", "toe": "diamond",
   }
   ```
   A downstream geometry pass may consult this when a prescription requests variable stiffness without naming a family per zone. Must not change current defaults (default `Fill` is all-solid).
6. **Update `SYSTEM_PROMPT`** (L22-41). Add a rule to the "Rules:" list, mirroring how mods/landmarks/ranges are enumerated. It must instruct:
   - Emit `fill` (on `left`/`right`) **only** when the text explicitly calls for variable stiffness / softer-or-firmer zones / lattice / infill (e.g. "softer heel", "firmer forefoot"). Otherwise leave `fill` unset (part stays solid).
   - Allowed families `solid|gyroid|diamond|primitive`; `density` 0.0–1.0 where `1.0`=solid; zones `heel|midfoot|forefoot|toe`.
   - On unclear/contradictory/out-of-range fill requests, set `needs_manual=true` and record the reason in `ambiguities`. Never invent fill zones the text didn't call for.

   No change to `parse_prescription` — it delegates to `output_format=Prescription`; the new field flows through once schema + prompt are updated.

**Guardrails.** No signature changes in `geometry.py` (esp. `generate_orthotic` and its 6-tuple). Don't modify the `Mod` union (L38) or `apply_mods` order. Solid default mandatory: `fill=None` and every `ZoneFill` default reproduces current output (geometry ignores `fill` this item). Don't touch `MIN_THICKNESS_MM`/watertightness/`validate`. Old fill-absent JSON must still validate against `Prescription`/`FootRx`; confirm `parse_prescription` and `app.py`'s `FootRx(**req.rx)` accept both fill-absent and fill-present dicts. `run_demo.py` runs unchanged.

**Acceptance.**
1. `python -c "import schema; schema.FootRx(); schema.FootRx(**{'mods':[]}); print(schema.DEFAULT_ZONE_LATTICE)"` — no error; prints `heel=primitive, midfoot=diamond, forefoot=gyroid, toe=diamond`.
2. `python -c "from schema import FootRx; print(FootRx(**{'mods':[]}).model_dump()['fill'])"` prints `None`.
3. `FootRx(fill={'heel':{'family':'primitive','density':0.3}})` → ok; `density=1.5` raises `ValidationError`; `family='honeycomb'` raises `ValidationError`.
4. `python run_demo.py` completes (~12s), report `"pass": true` with the same checks — geometry unchanged.
5. Parser (needs `ANTHROPIC_API_KEY`, else inspect prompt statically): `"4 degree medial wedge both feet"` → `left.fill`/`right.fill` absent/None, `needs_manual=false`. `"softer heel, firmer forefoot"` populates `fill` on the relevant foot within range (else `needs_manual=true` + `ambiguities`).
6. `grep -n "fill\|LatticeFamily\|DEFAULT_ZONE_LATTICE" schema.py` and `grep -ni "fill\|lattice\|density" rx_parser.py` show the new contract + prompt rule.

**Effort: S.**

---

## 4. Variable-stiffness lattice interior generator (TPMS SDF + marching cubes)

**Objective.** Add a module that replaces the fully-solid orthotic interior with a watertight, printable TPMS lattice whose local volume-fraction follows a per-zone density field, smoothly blended across zone boundaries, while preserving the shell's outer surface and the `MIN_THICKNESS_MM` clamp. Solid fill stays the default and is the 100%-density limit of the same code path.

**Why.** Zoned lattices cut peak plantar pressure 36–42% vs uniform infill (Frontiers 2026); solid is the 100%-density end of the same dial.

**Depends on item 3's schema.** This section **consumes** the per-zone density field defined in `schema.py` (`FootRx.fill` → per-zone `ZoneFill{family, density}`); do not redefine it. **Confirm the final field name/shape in `schema.py` at implementation time.**

**Files.**
- **New:** `lattice.py` — all TPMS/SDF/marching-cubes logic. Importable, side-effect-free.
- `geometry.py` — call the module from `generate_orthotic` (L293-309) after `solid_from_heightfield`, before export/validate.
- `requirements.txt` — add `scikit-image` (`skimage.measure.marching_cubes`; NOT currently imported — geometry uses only numpy, trimesh, scipy.ndimage, scipy.interpolate.griddata) **and `manifold3d`** (the trimesh boolean backend used in step 6; current geometry uses no booleans, so no backend is guaranteed in the venv, and without one trimesh booleans raise or return empty → `is_watertight` fails on every lattice case). Confirm both install on the 3.11 `.venv`.

**Approach.**
1. **Entry point / no-op default:**
   ```python
   def apply_lattice(solid: trimesh.Trimesh, hf: Heightfield, top, mask, rx: FootRx) -> trimesh.Trimesh:
   ```
   `solid, hf, top, mask` are elements 1,3,4,5 of the `generate_orthotic` tuple. If `rx` has no lattice request — `fill` absent, OR every zone is `family=="solid"`, OR density 1.0 everywhere — **return `solid` unchanged** (a true no-op). Treat `family=="solid"` as forcing solid for that zone **regardless of its `density` value** (e.g. `solid`+0.3 is still solid), so `density` only bites for the TPMS families.
2. **Per-zone density field on the heightfield grid.** Produce `dens[j,i]` over `(hf.ny, hf.nx)` (same shape as `top`/`mask`), one value in `[0,1]` per masked cell. **The schema's `Zone` literals (`heel|midfoot|forefoot|toe`) are NOT valid landmark names** — `hf.landmark("midfoot")` raises `ValueError` (L152-171). Map each zone to a concrete landmark (or a longitudinal band) explicitly:
   ```python
   ZONE_TO_LANDMARK = {
       "heel":     "heel_center",
       "forefoot": "met_heads",
       "toe":      "hallux",
       "midfoot":  "arch_apex",   # if arch_apex is unavailable, use a yn()-band fallback
   }
   ```
   `hf.landmark(name)` returns `(row,col)` and only accepts `heel_center`, `base_5th_met`, `met_heads`, `arch_apex`, `hallux` (else `ValueError`). Seed each zone at its mapped landmark cell. For any zone lacking a clean landmark (notably `midfoot`), fall back to a `yn()`-style longitudinal band along +Y (heel→toe) rather than a point seed. Then **blend smoothly** with a Gaussian/EDT falloff — reuse `scipy.ndimage.gaussian_filter`, `scipy.ndimage.distance_transform_edt`, and the `_smoothstep(t)=t*t*(3-2t)` helper (L176-178). Density is per-XY-column, extruded constant in Z (thin-shell approximation — note as a limitation).
3. **Evaluate the TPMS implicit field on a 3D voxel grid.** Cover `solid.bounds` at pitch ≈ `CELL_MM/2` = 1.0 mm or finer; unit-cell period `L` tunable (6–10 mm). `np.meshgrid(..., indexing='ij')`, `k = 2*np.pi/L`, default gyroid:
   ```python
   F = np.sin(x)*np.cos(y) + np.sin(y)*np.cos(z) + np.sin(z)*np.cos(x)   # x,y,z = k*X,k*Y,k*Z
   ```
   Dispatch on the schema's `ZoneFill.family` literal (`solid|gyroid|diamond|primitive` — item 3 defines the field as **`family`, NOT `pattern`**; confirm in `schema.py` at implementation time): `gyroid` as above; `primitive` (Schwarz Primitive) `cos x + cos y + cos z`; `diamond` (Schwarz Diamond) `cos x*cos y*cos z - sin x*sin y*sin z`. `solid` is handled by the no-op / 100%-density limit (step 1), not meshed as a TPMS field. Any unexpected family falls back to gyroid with a recorded warning.
4. **Threshold to prescribed local density.** Thickened-strut form `solid_field = |F| - wall`, extract `level=0` (meshed region `|F| <= wall`). The wall↔density map is **nonlinear** and TPMS-type-specific — **calibrate numerically** (measure occupied-voxel fraction); do NOT assume a closed form. Approx gyroid anchors: `t 0.0→~50%`, `0.4→~35%`, `0.8→~20%`. Since density varies in XY, build a spatially-varying `wall[j,i]` interpolated onto the voxel grid so wall thickness tracks `dens` smoothly.
5. **Mesh the field:**
   ```python
   from skimage import measure
   verts, faces, normals, _ = measure.marching_cubes(solid_field, level=0.0, spacing=(px,py,pz))
   lattice_mesh = trimesh.Trimesh(vertices=verts, faces=faces, vertex_normals=normals)
   ```
   Offset `verts` by `solid.bounds[0]` into the solid's world frame. (Use unified `marching_cubes`, not the removed `_lewiner`/`_classic` names.)
6. **Intersect with the shell + cap for watertightness / outer surface / min-thickness.** The outer surface and `MIN_THICKNESS_MM=2.0` clamp are already baked into `solid` (via `apply_mods` L224/L226 and `solid_from_heightfield`). `result = solid.intersection(lattice_mesh)` so the outer skin/floor come from `solid` (this requires the `manifold3d` boolean backend added to `requirements.txt` above — verify `trimesh.boolean` picks it up in the venv; without a backend the intersection raises or returns empty). To guarantee a solid skin, union a thin inward-offset "wall shell" of `solid` with the intersected lattice so there is always ≥ `MIN_THICKNESS_MM` of solid at the boundary before the lattice begins. Verify `result.is_watertight`; run `result.fix_normals()` and invert if `result.volume < 0` (mirror the `solid_from_heightfield` convention).
7. **Wire into `generate_orthotic`.** After `solid = solid_from_heightfield(top, mask, hf)` and the left-foot mirror/volume-sign fixups (L302-304), insert `solid = apply_lattice(solid, hf, top, mask, rx)` **before** `solid.export(out_stl)` (so export and `validate(solid, hf)` see the lattice result). Keep the 6-tuple return unchanged.
8. **No GPL / microgen.** Do **NOT** import `microgen` or add it to `requirements.txt` — it is GPL, and pulling it into a distributed STL-generating device product is a copyleft trap. Use **only** the self-contained trimesh/skimage path specified above; it is fully sufficient here.

**Guardrails.** `generate_orthotic` 6-tuple unchanged (`app.py` L95-101 keeps only `report`). `solid_from_heightfield`/`build_shell`/`apply_mods`/`validate` signatures unchanged. **Solid is the default** — no lattice field → byte-for-byte current solid path (early return). Preserve watertightness and the `MIN_THICKNESS_MM=2.0` clamp (lattice never thins the outer skin below it). `validate` thresholds still apply: `positive_volume` = `volume>1000`, length 120-360mm (`ext[1]`), width 40-140mm (`ext[0]`), height ≤60mm (`ext[2]`). A lattice lowering `volume_cm3` / `est_print_mass_g_tpu` (= `volume/1000*1.22`) is expected/desirable but must stay `>1000` mm³. `run_demo.py` completes end-to-end (keep added time bounded); don't commit generated output. Don't modify `schema.py` beyond consuming the field; don't touch `rx_parser.py`.

**Acceptance.**
1. `python -c "import skimage.measure, trimesh; print('ok')"` succeeds.
2. **Solid default unchanged:** `python run_demo.py` with no lattice field → same STLs/report (`pass=True`, `checks.watertight=True`); confirm the no-op branch is hit (temp log or identical volume vs baseline).
3. **Lattice path:** run with a lattice-bearing rx → `report["checks"]["watertight"] is True`, `positive_volume is True`, `pass is True`.
4. **Density reduces mass:** same scan/shell → `volume_cm3` and `est_print_mass_g_tpu` strictly lower with sub-1.0 density than solid, and monotonically decrease as prescribed density drops.
5. **Numeric calibration:** a callable check (e.g. `python -m lattice --calibrate`) prints measured occupied-voxel fraction vs target for gyroid at a few thresholds within a stated tolerance (e.g. ±5% absolute) — proving t↔density was measured, not assumed.
6. **Smoothness:** after blending, assert max cell-to-cell density gradient below a set bound (spot-check a two-zone rx: heel dense, forefoot soft).
7. `result.is_watertight == True` and `result.volume > 1000` for every demo case; exported STL reloads (`trimesh.load(..., force="mesh").is_watertight`) and slices without manifold errors.

**Effort: L.**

---

## 5. Formalize audit + complaint record to FDA 21 CFR 820.35

**Objective.** Harden the inline `approve()` audit write in `app.py` into a proper append-only Device History Record (DHR) — one immutable JSONL event per approval capturing the full scan → prescription → geometry → validation → approval chain — and add a minimal complaint-intake endpoint with its own append-only complaint log keyed to `result_id`/`order_id`. Stay in-file (JSONL), matching the current `outputs/audit_log.jsonl` style.

**Why.** Custom foot orthotics are Class I / 510(k)-exempt but still owe recordkeeping + complaint files (820.35). The append-only `approve()` log is 80% there; formalizing it is cheap and a genuine regulatory/trust moat.

**Files.** `app.py` — factor a shared append helper, expand the DHR in `approve()` (L122-134), add complaint endpoints. New durable artifacts under `outputs/`: keep `audit_log.jsonl`, add sibling `complaints.jsonl` (both created lazily; dir already `mkdir(exist_ok=True)` at L25-29). No `schema.py`/`geometry.py`/`rx_parser.py` changes. Optional small `ComplaintRequest` Pydantic model in `app.py` next to `ParseRxRequest`/`GenerateRequest`.

**Approach.**
1. **Single append-only writer:**
   ```python
   def _append_event(path: Path, event_type: str, payload: dict) -> dict:
       rec = {"event_type": event_type,
              "ts_utc": datetime.now(timezone.utc).isoformat(),
              "prev_hash": _tail_hash(path), **payload}
       rec["record_hash"] = hashlib.sha256(
           json.dumps(rec, sort_keys=True, separators=(",", ":")).encode()).hexdigest()
       with open(path, "a") as f:
           f.write(json.dumps(rec) + "\n")
       return rec
   ```
   Use `datetime.now(timezone.utc).isoformat()` — the current `time.strftime(...)` is local-time/naive, inadequate for a regulatory record. Keep the existing `approved_at` field if the UI reads it, but add the UTC ISO field as authoritative.
2. **Cheap hash chain.** `_tail_hash(path)` reads the last line's `record_hash` (or `"GENESIS"` if file absent/empty); each new record embeds it as `prev_hash` then hashes itself. Single-line tail read, stdlib only.
3. **Expand the DHR payload in `approve()`.** The current record writes 8 keys (`result_id, order_id, side, rx, shell, rx_text, report, approved_at`). `RESULTS[result_id]` (L103-108) already aggregates everything. Additionally capture:
   - **Scan identity** — from `r["scan"]`: `filename`, stored `path`, and `scan_sha256` (sha256 of the bytes at `scan["path"]`).
   - **Prescription provenance** — `rx_text` (raw), `rx` (parsed `FootRx.model_dump()`), and `parser_model` = `rx_parser.MODEL` (`"claude-opus-4-8"`, rx_parser.py L20 — import and record it). Note `generate()` accepts a pre-parsed `rx` dict and doesn't call `parse_prescription`, so record `parser_model` as best-effort and add a `# TODO` that a caller-supplied provenance flag would make this exact.
   - **Shell + mods** — `r["shell"]` (`Shell.model_dump()`) and the applied-mod order from `report["mods_applied"]`.
   - **Validation report** — the full `r["report"]` (`pass`, `checks`, `volume_cm3`, `extents_mm`, `warnings`, `foot_length_mm`, `generation_seconds`).
   - **Output STL identity** — `r["stl"]` path + `stl_sha256` (sha256 of the exported STL bytes).
   - **Reviewer approval** — `approved_at` (existing) + `ts_utc`; `"reviewer": None  # TODO: populate when auth lands`.
4. **Complaint intake endpoint** (mirror `approve()`/`get_stl()` — look up `RESULTS.get(result_id)`, 404 if missing):
   ```python
   class ComplaintRequest(BaseModel):
       narrative: str
       category: str = "unspecified"
       reporter: str = "anonymous"     # TODO: no PII handling / auth yet

   @app.post("/api/complaint/{result_id}")
   def file_complaint(result_id: str, req: ComplaintRequest):
       r = RESULTS.get(result_id)
       if not r:
           raise HTTPException(404, "Result not found")
       rec = _append_event(OUTPUTS / "complaints.jsonl", "complaint",
                   {"result_id": result_id, "order_id": r["order_id"],
                    "side": r["side"], "narrative": req.narrative,
                    "category": req.category, "reporter": req.reporter})
       return {"ok": True, "complaint_id": rec["record_hash"][:12]}
   ```
   Denormalize `order_id` from the result so complaints tie back to the DHR even after in-memory `RESULTS` is lost on restart.
5. **Read endpoints** (mirror `list_results()` L137, read-only, no delete/edit): e.g. `@app.get("/api/complaints")` and/or `@app.get("/api/device_history/{result_id}")` that stream matching JSONL lines.
6. **Document the SQLite migration path** in a comment where the writer lives (echo L33's "swap for SQLite when multi-user"): JSONL maps 1:1 to an `events` table (`event_type, ts_utc, prev_hash, record_hash, payload_json`) and a `complaints` table keyed by `result_id`; hash-chain columns port directly. Do not implement SQLite now.
7. **Auth/PII:** do NOT add auth or PII handling. Leave explicit `# TODO(820.198/Part 11): reviewer identity, signature, PII handling` markers at `reporter`, `reviewer`, and the endpoints.

**Guardrails.** No `generate_orthotic`/geometry signature changes — this only reads `report` and file paths. Don't alter frontend-facing response shapes: `approve()` still returns `{"ok": True, "download_url": ...}`; `generate()` still `{"result_id","report","stl_url"}`; `list_results()` unchanged. New fields go in the JSONL record, not HTTP responses (except the new complaint routes). Existing `outputs/audit_log.jsonl` lines must stay readable — readers tolerate old 8-key lines; treat pre-existing lines as `prev_hash="GENESIS"` predecessors (confirm desired behavior in code). Stdlib only — no `requirements.txt` changes. `run_demo.py` runs unchanged (no geometry/schema touched).

**Acceptance.**
- `python run_demo.py` still completes (~12s) with a passing report — geometry/schema untouched.
- Start `python app.py`; drive `/api/upload` → `/api/generate` → `/api/approve/{result_id}`. Then:
  - `outputs/audit_log.jsonl` gains exactly one line; it contains at minimum `event_type`, `ts_utc` (UTC ISO-8601 with offset), `scan` filename + `scan_sha256`, `rx_text`, `rx`, `parser_model == "claude-opus-4-8"`, `shell`, `report` (with nested `checks`), `stl_sha256`, `record_hash`, `prev_hash`.
  - `ts_utc` parses via `datetime.fromisoformat` and is timezone-aware.
- POST `/api/complaint/{result_id}` with `{"narrative":"arch pressure"}` → `{"ok":true,...}`; `outputs/complaints.jsonl` gains one line with `result_id`, `order_id`, `narrative`, `record_hash`. Bogus id → HTTP 404.
- Hash-chain check: edit a middle `narrative` in `complaints.jsonl`; a verifier loop (recompute each `record_hash`, compare to stored, confirm each `prev_hash` matches predecessor) reports a break at the tampered line, all prior lines intact.
- `grep -n "sqlite\|# TODO" app.py` shows the migration comment and auth/PII TODOs but no auth code.

**Effort: S.**

---

## Definition of done

- [ ] **Item 1:** `pymeshlab` imports (top-level only if the venv wheel is confirmed installed, else local to `clean_scan`); `clean_scan` runs the repair recipe with warnings threaded into `report["warnings"]`; holey-input smoke test shows improved watertightness; decimation budget and `heavy_repair=False` skip path both verified; `run_demo.py` and `/api/generate` still pass.
- [ ] **Item 2:** `vendor/ampscan_icp.py` (+ `__init__.py`, `LICENSE.ampscan`) vendored with MIT attribution; template asset checked in **and verified in-frame via `align_canonical`**; ICP refines after PCA inside `align_canonical`, falls back gracefully, and surfaces the residual warning when over threshold; both chiralities correct; `run_demo.py` green.
- [ ] **Item 3:** `schema.py` has `LatticeFamily`, `Zone`, `ZoneFill`, `Fill`, `DEFAULT_ZONE_LATTICE`, and optional `FootRx.fill=None`; range/enum validation enforced; old fill-absent JSON still validates; `SYSTEM_PROMPT` emits `fill` only on explicit requests; `run_demo.py` output unchanged.
- [ ] **Item 4:** `lattice.py` + `scikit-image`/`manifold3d` deps; `apply_lattice` is a true no-op for solid default (incl. `family=="solid"` regardless of density) and produces a watertight, min-thickness-preserving lattice for lattice rx; families dispatch on `ZoneFill.family`; zones map to real landmarks; mass drops monotonically with density; numeric density calibration and smoothness both proven; no GPL/microgen; `validate` stays green (`volume>1000`, watertight).
- [ ] **Item 5:** `_append_event` + hash chain; expanded DHR in `approve()` with scan/STL sha256, parser_model, full report; `/api/complaint/{result_id}` + read endpoints; UTC ISO timestamps; tamper detection works; stdlib only; existing HTTP response shapes unchanged.
- [ ] **Every item:** smallest change, no unrelated refactors, public signatures/return shapes preserved, `python run_demo.py` passes (`report["pass"] == True`, watertight, positive volume, plausible dims) before moving on; new deps added to `requirements.txt`; no generated `.stl`/`.obj`/PNG committed.

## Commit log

2026-07-10 Set up repo for local dev: add CLAUDE.md, .gitignore, static/ folder
    app.py mounts static/ for the review UI but that directory didn't exist;
    copy index.html there so the FastAPI server can actually serve it.
2026-07-10 Add Claude Rx-parser: free-text prescription -> validated Prescription
    rx_parser.py calls Claude (claude-opus-4-8) with structured outputs pinned
    to the existing Pydantic schema, flagging ambiguities instead of guessing.
    Exposed as POST /api/parse_rx and wired into the review UI as a
    "Parse Rx with Claude" button that pre-fills the mod panel for reviewer
    confirmation. Requires ANTHROPIC_API_KEY.
2026-09-10 chore: checkpoint imported Orthopipe prototype
    [right_foot_template.stl]
2026-09-10 feat: add fabrication print preparation workflow
